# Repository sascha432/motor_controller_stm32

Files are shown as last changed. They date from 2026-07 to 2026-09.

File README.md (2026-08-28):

# DC Motor Controller Firmware for STM32F107/DRV8701

## Software Features

- Start/dashboard workflow for quick motor start-stop and live runtime status
- Selectable control mode: PWM open-loop or RPM-based PID closed-loop
- On-device tuning for speed, brake strength, and stall timeout
- Configurable protection limits for input current, motor current, MOSFET temperature, and motor temperature
- Advanced setup for RPM range, motor direction, and sensor direction
- PID parameter tuning (Kp, Ki, Kd, anti-windup) with live parameter apply and graph
- Diagnostics screen with firmware/PCB info and live min/max telemetry (VCC, current, temperatures, RPM/PWM)
- EEPROM-backed settings with save/restore-defaults from the menu
- LVGL TFT UI with rotary encoder plus dedicated start/back/knob buttons
- Python Tool for configuration and parameter tuning over SWD or USB serial connection

## [Change Log](docs/CHANGELOG.md)

## Hardware Features

- 8-36V, 20A continuous, 40A peak
- Adjustable cycle by cycle motor current limit (0.5-40A)
- Adjustable current limit with signal LED (0.5-40A)
- 1.14" 135x240 TFT display, rotary encoder and 3 buttons for easy navigation
- Support for magnetic encoder MT6701 in A/B mode up to 1024PPR (55000 RPM)
- Dimmable LED with CC driver 3-32V/350mA/5W
- Current, voltage and temperature monitoring

## Current and voltage protection

### Undervoltage Lockout

The controller has an undervoltage lockout (UVLO) threshold of 5.9V. When the supply voltage drops below this threshold, the motor is disabled briefly to allow the supply voltage to recover.

The red LED indicates an undervoltage condition and turns off after the voltage recovers.

### Overvoltage Protection

Overvoltage protection (OVP) is most likely to be triggered while the motor is braking. Back EMF can cause a substantial increase in the supply voltage, potentially blowing the fuse. Adjust the braking strength and OVP threshold carefully; a limit of 32V is generally safe.

At approximately 38V and above, the OVP is disabled, causing all of the energy to be dissipated through the clamping diode and fuse. When OVP is triggered, braking is disengaged, the red LED turns on, and the display shows a motor OVP error.

### Overcurrent Protection

The controller has three configurable current-protection mechanisms.

**NOTE:** the PID parameters must be well tuned for the current limit to work correctly. This applies to closed-loop (RPM-based) mode only.

#### Motor Current Limit

> The maximum current through the motor winding is regulated by a fixed off-time PWM current regulation, or current chopping. When an H-bridge is enabled in forward or reverse drive, current rises through the winding at a rate dependent on the DC voltage and inductance of the winding. After the current hits the current chopping threshold, the bridge enters a brake (low-side slow decay) mode until tOFF has expired.<br>(TI DRV8701 SLVSCX5B –MARCH 2015–REVISED JULY 2015)

This protection operates silently and does not generate a user-facing error.

#### Input Current Limit

When the maximum input current is reached, the motor current limit is gradually reduced until the condition clears. It is then gradually increased again to prevent immediate retriggering. If the motor current limit is set too low, the input current limit may not function correctly.

The yellow LED indicates that the input current limit has been reached and turns off after recovery.

#### Current Limit Strength

The current limit strength determines how fast the motor current is reduced once the input current limit is reached, and how quickly it is restored again after the condition clears. A higher strength reacts more aggressively, whereas a lower strength smooths the reduction and recovery to avoid abrupt current changes.

## Error Codes

The red LED blinks once to indicate an error. The yellow LED then identifies
the error by blinking the corresponding number of times:

| Yellow LED flashes | Description |
|---:|---|
| 1 | A general error was reported |
| 2 | The watchdog interrupt did not respond in time (57ms) |
| 3 | The watchdog timer was not reset in time (1000ms) |
| 4 | The processor encountered a severe, unrecoverable error |
| 5 | The processor accessed memory incorrectly |
| 6 | A critical interrupt occurred that could not be ignored |
| 7 | The processor accessed an invalid or unavailable bus address |
| 8 | The processor detected an invalid instruction or arithmetic operation |

## Navigation

### Rotary Knob Button

- Start screen: open main menu (long press opens advanced menu)
- Dashboard screen: select next value to change (RPM/PWM/PID parameters, etc.), long press selects prev. value

### Start Button

- Start screen: start motor
- Dashboard screen: stop motor

### Back Button

- Start screen: toggle motor direction
- Dashboard screen: stop motor
- Menus: go back to previous menu
- Long press (5 seconds): firmware reset

## Controller schematics and PCB

[Schematics & PCB](https://oshwlab.com/sascha23095123423/project_dzierqaj)

[Schematics PDF](docs/schematic_dc-motor-controller_rev11.pdf)

[Schematics SVG](docs/schematic_dc-motor-controller_rev11.svg)

<a href="docs/schematic_dc-motor-controller_rev11.svg">
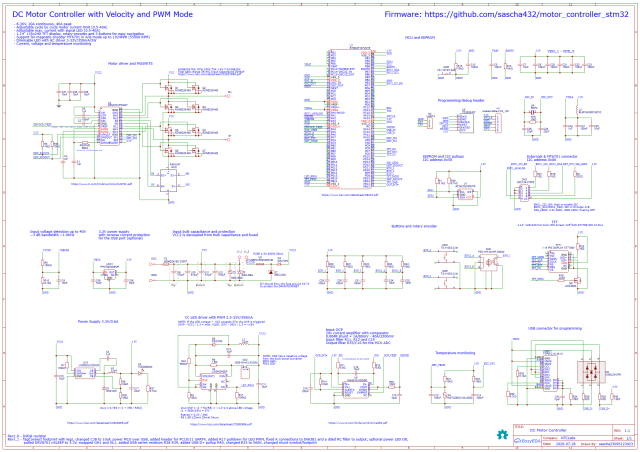
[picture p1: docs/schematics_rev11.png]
Schematic thumbnail
	
</a>

## STL files for motor mount and enclosure

[STL files](stl/STL.md)

## Some pictures

Demonstration of the DC motor controller running a drill press motor

DC motor controller demonstration (https://www.youtube.com/watch?v=RS3WaWhKhmE)

Screenshots

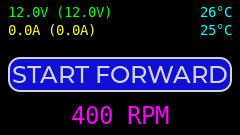
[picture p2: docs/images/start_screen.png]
start_screen

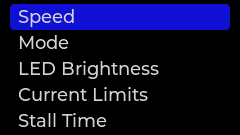
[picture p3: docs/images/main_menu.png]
main_menu

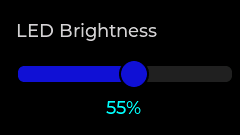
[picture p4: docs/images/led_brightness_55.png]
led_brightness_55


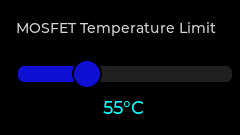
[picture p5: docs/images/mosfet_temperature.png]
mosfet_temperature

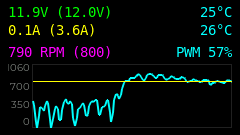
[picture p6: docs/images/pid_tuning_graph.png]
pid_tuning_graph

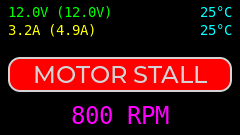
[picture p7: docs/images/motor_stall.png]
motor_stall


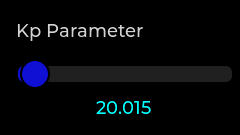
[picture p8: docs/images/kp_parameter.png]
kp_parameter

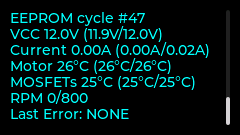
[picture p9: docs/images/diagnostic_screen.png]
diagnostic_screen


Drill press, controller enclosure and PCB

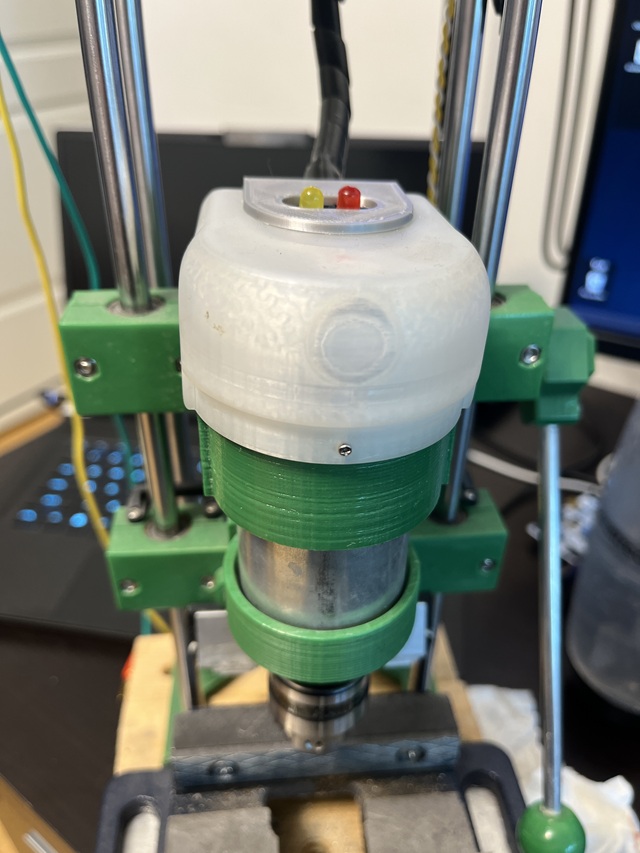
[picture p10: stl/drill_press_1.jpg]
Drill press


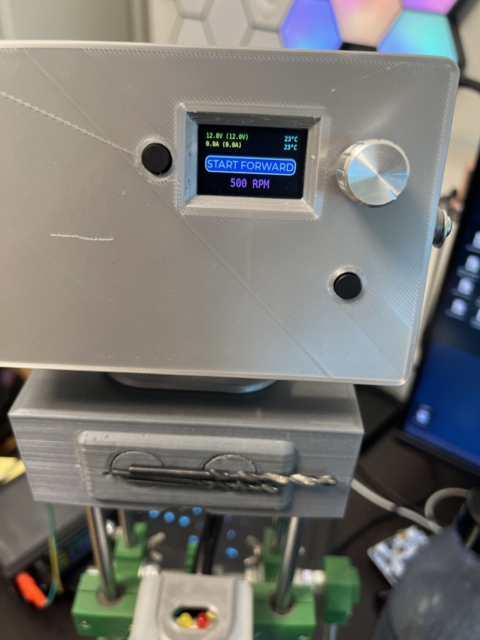
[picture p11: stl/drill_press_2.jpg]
Drill press


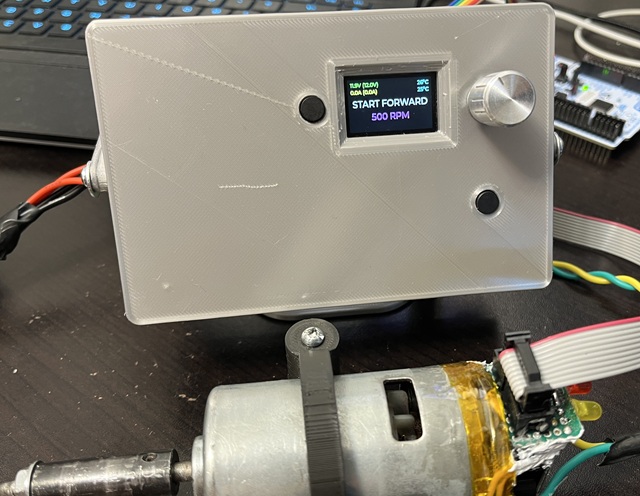
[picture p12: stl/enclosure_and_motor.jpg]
Enclosure and motor


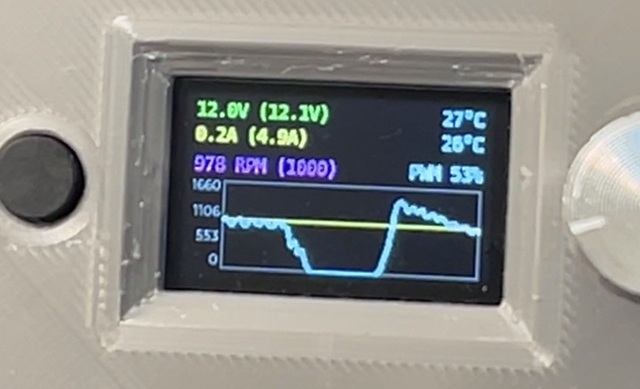
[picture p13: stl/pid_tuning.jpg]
PID tuning


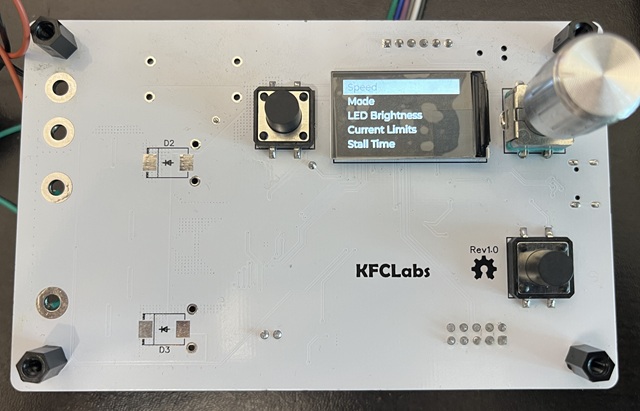
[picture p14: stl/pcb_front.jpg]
PCB front


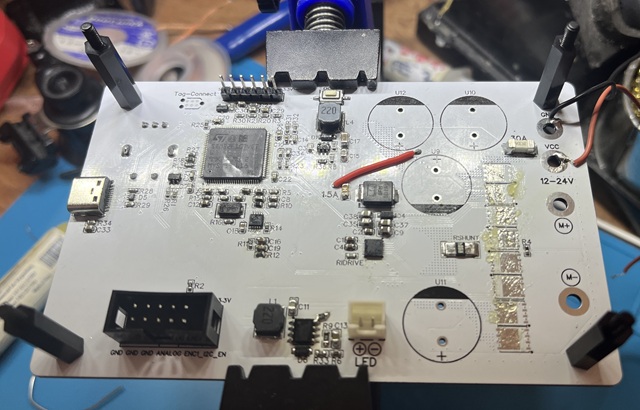
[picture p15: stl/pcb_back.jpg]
PCB back


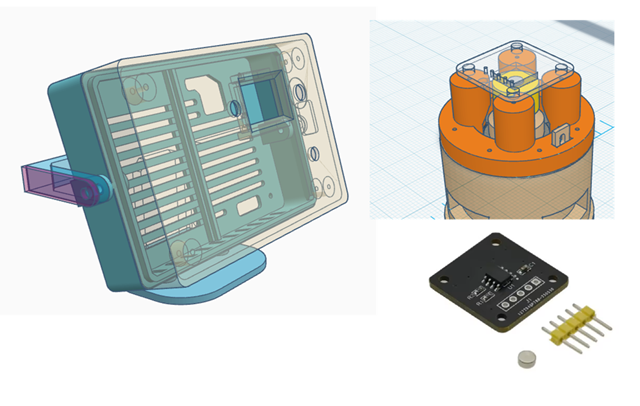
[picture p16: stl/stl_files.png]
STL files and MT6701


PID tuning software

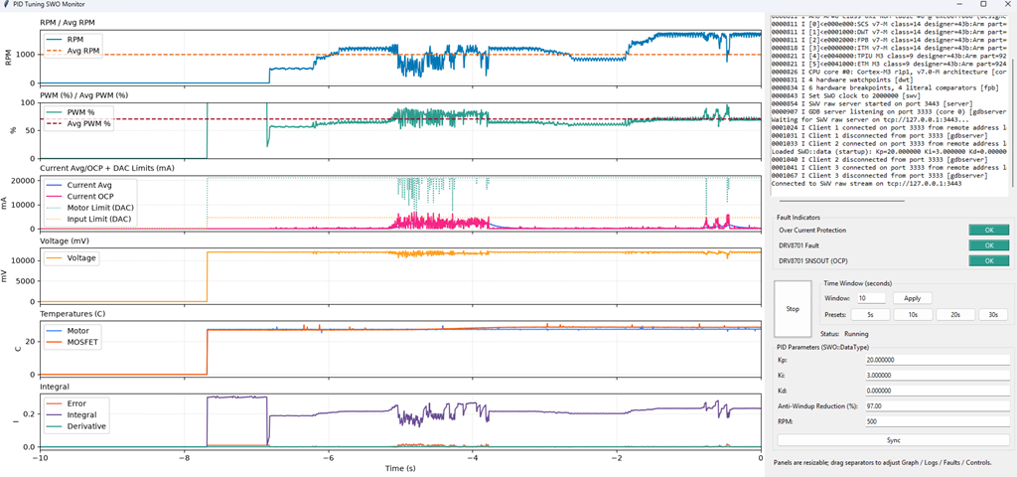
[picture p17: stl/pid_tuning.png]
PID tuning


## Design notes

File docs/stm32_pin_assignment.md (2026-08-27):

<style>
table {
	width: 100%;
	table-layout: fixed;
}
th:nth-child(1), td:nth-child(1) { width: 22%; }
th:nth-child(2), td:nth-child(2) { width: 12%; }
th:nth-child(3), td:nth-child(3) { width: 12%; }
th:nth-child(4), td:nth-child(4) { width: 56%; }
</style>

# STM32F107VCT6 - pin assignments

## Revision: PCB Rev1.0

### DAC output

| Signal | STM32 pin | Type | Notes |
|---|---|---|---|
| DRVOCP_VREF | PA4 | DAC | DAC1_OUT1 |
| OCP_VREF | PA5 | DAC | DAC1_OUT2 |

### ADC input

| Signal | STM32 pin | Type | Notes |
|---|---|---|---|
| EXT_NTC | PC4 | ADC | ADC12_IN14 |
| DRV_TEMP | PC5 | ADC | ADC12_IN15 |
| ISENSE | PA2 | ADC | ADC12_IN2 |
| VSENSE | PA3 | ADC | ADC12_IN3 |
| ENC1_ANALOG | PA1 | DIN | ADC12_IN1/TIM5_CH2 counter |

### QDEC - rotary encoder ENC2

| Signal | STM32 pin | Type | Notes |
|---|---|---|---|
| ENC2_A | PA6 | QDEC | TIM3_CH1 |
| ENC2_B | PA7 | QDEC | TIM3_CH2 |

### QDEC - MT6701 magnetic encoder ENC1

| Signal | STM32 pin | Type | Notes |
|---|---|---|---|
| ENC1_SCL | PB6 | QDEC/I2C | TIM4_CH1 / I2C1_SCL |
| ENC1_SDA | PB7 | QDEC/I2C | TIM4_CH2 / I2C1_SDA |

### PWM output - motor 40 kHz

| Signal | STM32 pin | Type | Notes |
|---|---|---|---|
| DRV_IN2 | PA9 | PWM | TIM1_CH2 |
| DRV_IN1 | PA8 | PWM | TIM1_CH1 |

### PWM output - 1 kHz

| Signal | STM32 pin | Type | Notes |
|---|---|---|---|
| LED_PWM | PB10 | PWM | TIM2_CH3 (remap) - CC LED driver |
| TFT_PWM | PB11 | PWM | TIM2_CH4 (remap) - TFT backlight |

### SPI - TFT display

| Signal | STM32 pin | Type | Notes |
|---|---|---|---|
| TFT_DC | PC7 | DOUT SPI | GPIO data/command |
| TFT_RST | PC6 | DOUT SPI | GPIO reset |
| TFT_CS | PD15 | DOUT SPI | GPIO chip select |
| TFT_MOSI | PB15 | SPI2 | SPI2_MOSI |
| TFT_CLK | PB13 | SPI2 | SPI2_SCK |

### I2C

| Signal | STM32 pin | Type | Notes |
|---|---|---|---|
| SDA1 | PB9 | I2C1 | I2C1_SDA (remap) - 5.1 kOhm pull-up |
| SCL1 | PB8 | I2C1 | I2C1_SCL (remap) - 5.1 kOhm pull-up |

### USB

| Signal | STM32 pin | Type | Notes |
|---|---|---|---|
| USB_DP | PA12 | USB | USB FS D+ |
| USB_DN | PA11 | USB | USB FS D- |

### Debug / programming - TagConnect 6-pin

| Signal | STM32 pin | Type | Notes |
|---|---|---|---|
| SWCLK | PA14 | SWD |  |
| SWDIO | PA13 | SWD |  |
| SWO | PB3 | SWD |  |

### Digital output

| Signal | STM32 pin | Type | Notes |
|---|---|---|---|
| ENC1_I2C_EN | PD7 | DOUT | Enables MT6701 I2C mode |
| MOTOR_LEDS | PD12 | DOUT | 220 Ohm series resistor, charlieplexed red and yellow |

### Digital input - fast interrupt

| Signal | STM32 pin | Type | Notes |
|---|---|---|---|
| DRV_SNSOUT | PD11 | DIN IRQ | Current sense output, falling |
| DRV_FAULT# | PB14 | DIN IRQ | Active-low - DRV8701 fault, falling |
| OCP_INT# | PB12 | DIN IRQ | Active-low - INA381 ALERT#, falling |

### Digital input - interrupt

| Signal | STM32 pin | Type | Notes |
|---|---|---|---|
| BTN_3 | PD10 | DIN IRQ | Start Button, 100 nF debounce cap, rising/falling |
| BTN_2 | PD9 | DIN IRQ | Back Button, 100 nF debounce cap, rising/falling |
| BTN_1 | PD8 | DIN IRQ | Rotary Knob, 100 nF debounce cap, rising/falling |

## Revision: PCB Rev1.1

### UART

| Signal | STM32 pin | Type | Notes |
|---|---|---|---|
| TX4 | PC10 | SERIAL | UART4 TX |
| RX4 | PC11 | SERIAL | UART4 RX |

## Revision: PCB Rev1.2

| Signal | STM32 pin | Type | Notes |
|---|---|---|---|
| USB_PU_EN | PE1 | DOUT | USB pull-up enable in conjunction with VBUS detection |

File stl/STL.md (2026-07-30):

# STL files

This folder contains the .STL files for the MT6701 encoder motor mount and the enclosure for the controller.

## TinkerCad Source files

### 775 Motor Mount For MT6701

https://www.tinkercad.com/things/627dToPH86K-775-motor-mount-for-mt6701-magnetic-encoder

#### Aliexpress MT6701 Module

MT6701 Magnetic Encoder Magnetic Induction Angle Measurement Sensor Module 14bit High Precision Replacement AS5600

The module requires some modifications to enable A/B mode. The controller supports programming over I2C and switching to A/B mode, if the mode selection pin is connected to the controller.

https://www.aliexpress.com/item/1005005796758249.html

### Controller Enclosure

https://www.tinkercad.com/things/fNIPaWNxDLo-motor-controller-enclosure

## Pictures

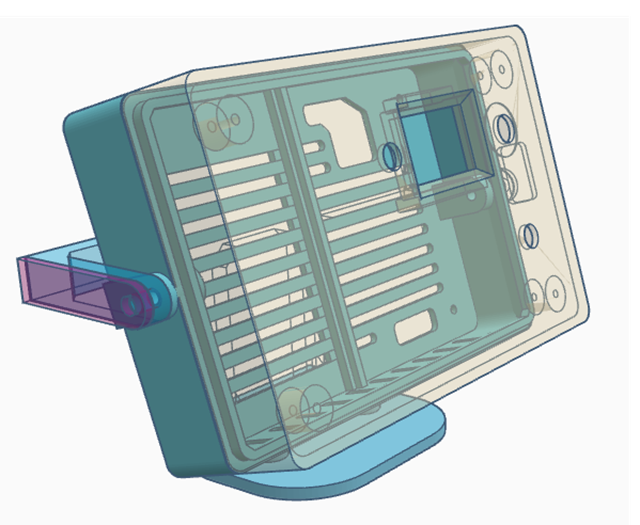
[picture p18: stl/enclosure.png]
Controller Enclosure


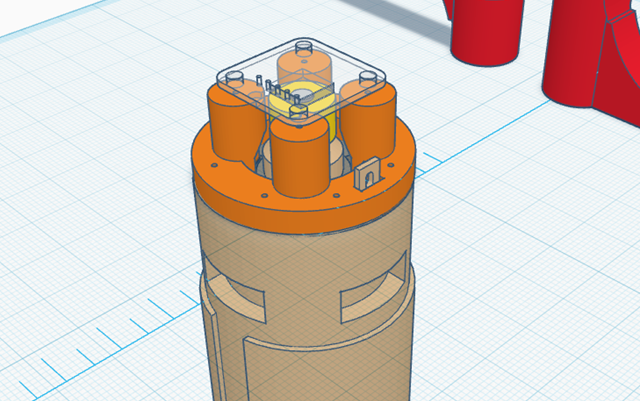
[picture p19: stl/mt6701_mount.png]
MT6701 Motor Mount


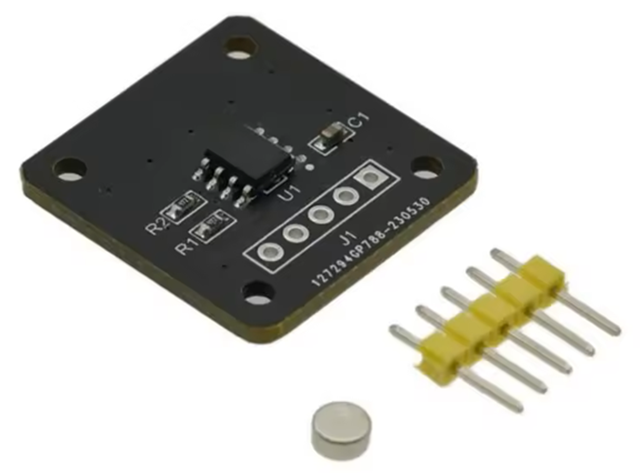
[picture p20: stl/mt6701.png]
MT6701 Module


PCB front

PCB back

Enclosure and motor

PID tuning

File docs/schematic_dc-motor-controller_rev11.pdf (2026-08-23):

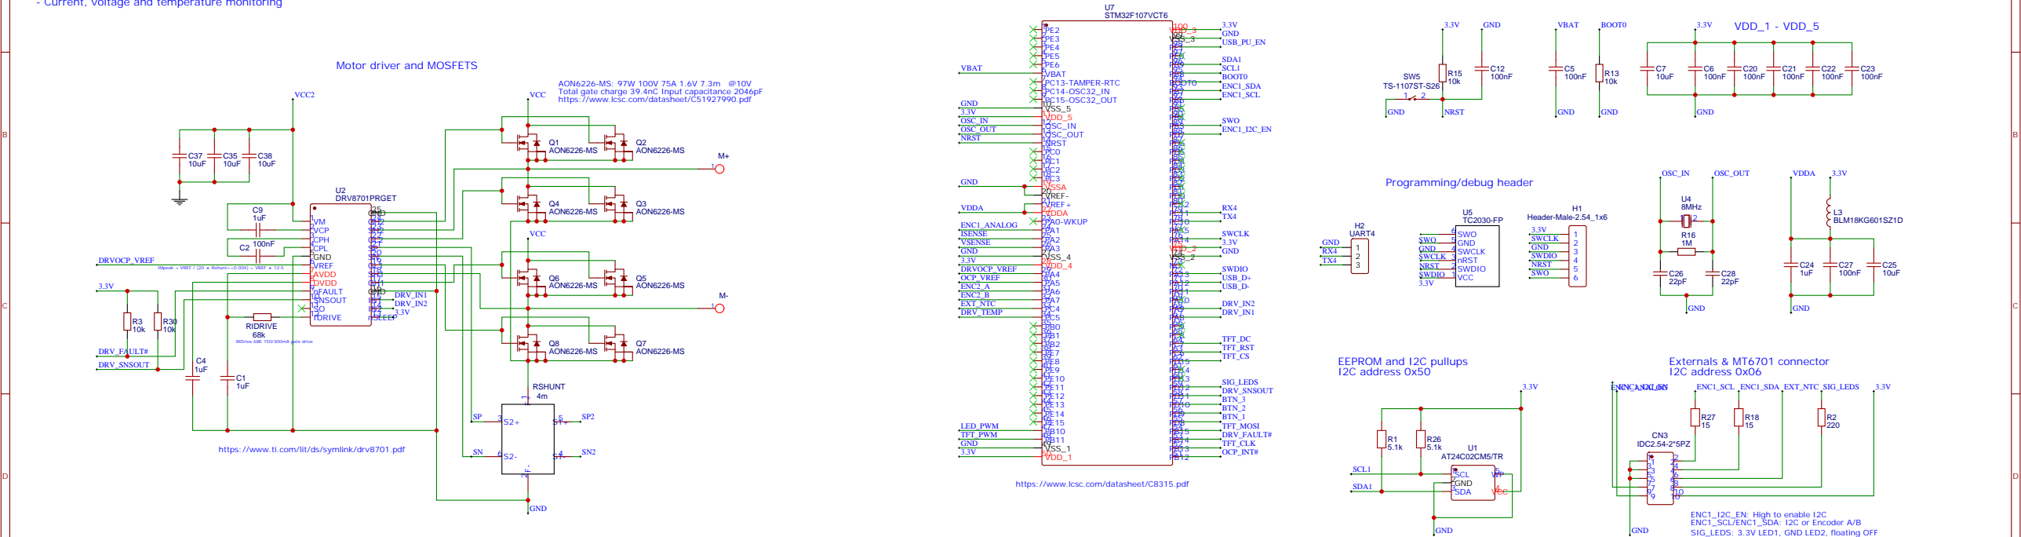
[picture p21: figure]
AON6226-MS; DRV8701PRGET; VM 1 VCP 2 CPH 3 CPL 4 GND 5 VREF 6 AVDD 7 DVDD 8 nFAULT 9 SNSOUT 10 SO 11; RIDRIVE; DRV_IN2; DRV_IN1; DRVOCP_VREF; IMpeak = VREF / (20; Rshunt==0.004) = VREF; RiDrive 68K 150/300mA gate drive; Motor driver and MOSFETS; DRV_FAULT#; STM32F107VCT6; 5 VBAT; 6 PC13-TAMPER-RTC; 7 PC14-OSC32_IN; 8 PC15-OSC32_OUT; 9 VSS_5; 10 VDD_5; 11 OSC_IN; 12 OSC_OUT; 13 NRST; 18 VSSA; 19 VREF-; 20 VREF+; 21 VDDA; 22 PA0-WKUP; 26 VSS_4; 27 VDD_4; 48 VSS_1; 49 VDD_1; VSS_2; VDD_2; BOOT0; VSS_3; VDD_3; SCL; 1 GND; 2 SDA; VCC; DRVOCP_VREF OCP_VREF; SDA1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

IDRIVE 12 | nSLEEP 13 IN214 IN115 GND 16 GH1 17 SH1 18 GL1 19 SN20 SP21 GL2 22 SH2 23 GH2 24 GND 25

## Input bulk capacitance and protection VCC2 is decoupled from bulk capacitance and fused

## CC LED driver with PWM 2.5-32V/350mA

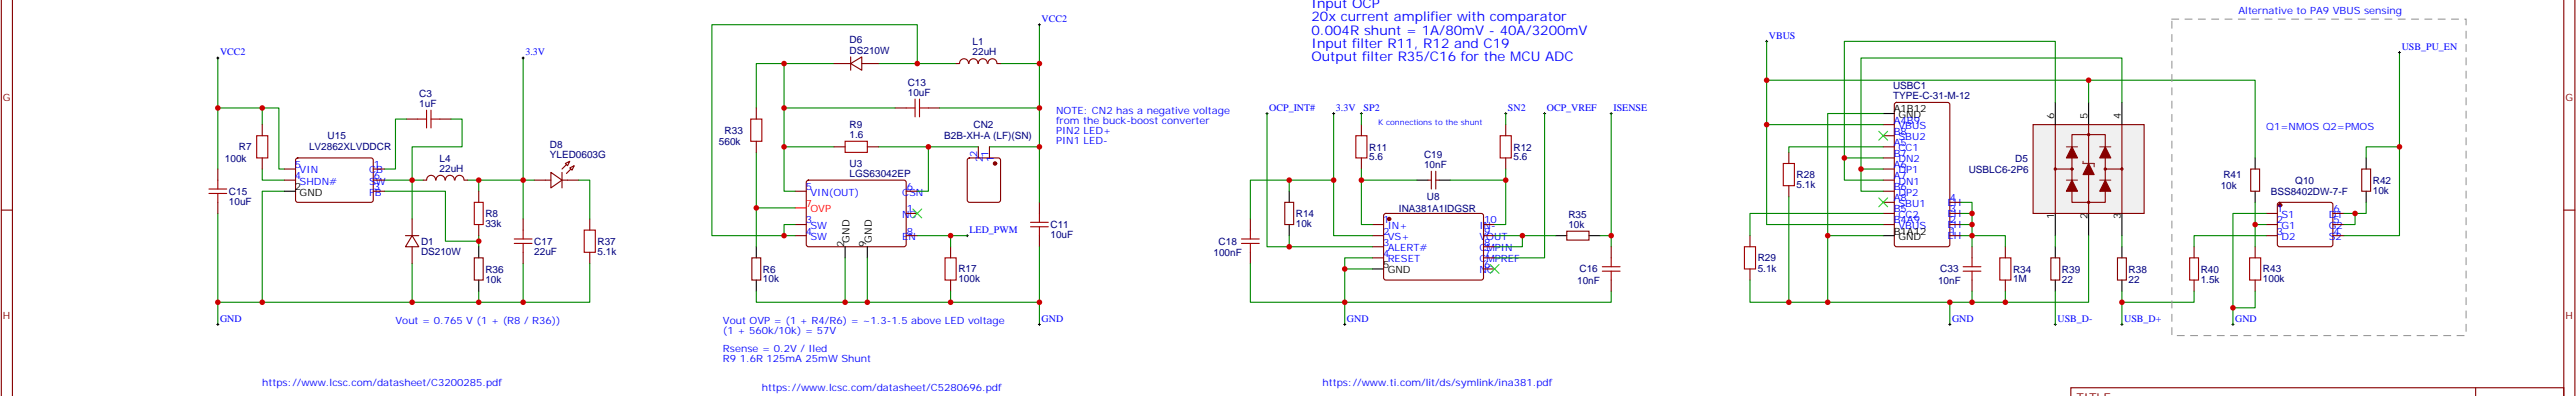
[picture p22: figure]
LED_PWM; LGS63042EP; VIN(OUT) 5; CSN 6; GND; OVP 7 SW3 SW4; INA381A1IDGSR; 10 VOUT; 9 CMPIN; 8 CMPREF; 6 GND; RESET; ALERT#; ISENSE; 20x current amplifier with comparator 0.004R shunt = 1A/80mV - 40A/3200mV Input filter R11, R12 and C19 Output filter R35/C16 for the MCU ADC; OCP_VREF; OCP_INT#; TYPE-C-31-M-12; USBC1; A1B12 VBUS; A4B9 SBU2; B6 SBU1; B5 VBUS; B4A9 GND; USBLC6-2P6; LV2862XLVDDCR; GND 2; SHDN# 4; VIN 5; Vout = 0.765 V (1 + (R8 / R36)); NOTE: CN2 has a negative voltage from the buck-boost converter PIN2 LED+ PIN1 LED-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

Vout OVP = (1 + R4/R6) = ~1.3-1.5 above LED voltage

A | A
E | E
F | F

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
### TITLE:

DC Motor Controller | REV: 1.2
Date: | 2026-07-28

### Sheet: 1/1

## Drawn By: sascha23095123423

### Company: KFCLabs

100k

R5

9.1k

R10

VSENSE

## Input voltage detection up to 40V 3 dB bandwidth ~1.9KHz

## Input OCP

## MCU and EEPROM

1.14 IPS DISPLAY ST7789V

TFT1

TP0

1
TP1

2
SDIN

3
SCLK

4
RS

5
RES

6
CS
7 | GND
| 8

NC

9

VDD

10

LED-

11

LED+

12

GND

13

PEC11R-4015F-S0024

SW1

B

C

A | 1
| 2

TS-1103S-C-M

SW2

3 | 4
1 | 2

TFT_CLK

TFT_MOSI

AO3400A

Q9

220

R19
TFT_PWM

TFT_RST
TFT_CS

TFT_DC
10k

R20

100nF

C29
100nF

C30

10k

R21
10k

R22

100nF

C31

10k

R23
10k

R24

10nF

C34
10nF

C32

BTN_1 | BTN_2 | BTN_3 | ENC2_A | ENC2_B

## Buttons and rotary encoder

ENC2_A | BTN_1

ENC2_B

TS-1103S-C-M

SW3

3 | 4
BTN_3 | 1 | 2

BTN_2

## TFT

15

R25

VCC

1

GND

1

1.14" 135x240 Full Color IPS Screen 135*240 ST7789 SPI 13 Pins

- 8-36V, 20A continuous, 40A peak - Adjustable cycle by cycle motor current limit (0.5-40A) - Adjustable max. current with signal LED (0.5-40A) - 1.14" 135x240 TFT display, rotary encoder and 3 buttons for easy navigation - Support for magnetic encoder MT6701 in A/B mode up to 1024PPR (55000 RPM) - Dimmable LED with CC driver 3-32V/350mA/5W - Current, voltage and temperature monitoring

# DC Motor Controller with Velocity and PWM Mode

10k

R31

DRV_TEMP

10k

R32

## Temperature monitoring

KNTC0603/10KJ3950

R4

EXT_NTC

470uF

U9
470uF

U10
470uF

U11
470uF

U12
SMCJ58A

D2

BSMD2410C-2300T

F2
F1206FA1500V063TM

U6

D7 should blow the fuse around 43.7V to protect the DRV8701PRGET

## USB connector for programming (optional) Power Supply 3.3V/0.6A

DS210W

D4

10nF

C8

SMCJ33A

D7

100nF

C10
100nF

C14

SMCJ58A

D3

J1_1

1

J1_2

1 VCCJP

Total gate charge 39.4nC Input capacitance 2046pF

Top | Bottom | Top Bottom

FUSE 1.5A 400% 50ms

## Rev1.0 - Initial revision

Rev1.1 - TagConnect footprint with legs, changed C38 to 10uF, power MCU over USB, added header for PC10/11 UART4, added R17 pulldown for LED PWM, fixed K connections to INA381 and a dded RC filter to output, optional power LED D8, pulled DRV8701 nSLEEP to 3.3V, swapped GH1 and GL1, added USB series resistors R38 R39, added USB D+ pullup R40, changed R33 to 560K, changed shunt symbol/footprint

## Rev 1.2 - Removed USB LDO (self powered) and added VBUS sensing

SIG_LEDS: 3.3V LED1, GND LED2, floating OFF

# Firmware: https://github.com/sascha432/motor_controller_stm32

VCCJP | VCC | VCC2
3.3V

3.3V

3.3V

GND | GND | GND | GND | GND

GND

NOTE: If the LED voltage + VCC exceeds 57V, the OVP is triggered (OVP - VCC) / 1.3 = max. VLED, (57V - 36V) / 1.3 = ~16V

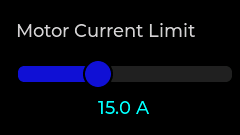
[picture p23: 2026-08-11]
docs/images/motor_current_limit.png

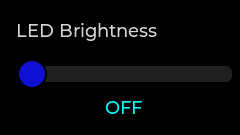
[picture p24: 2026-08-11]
docs/images/led_brightness_0.png

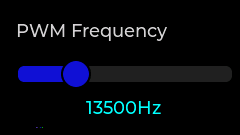
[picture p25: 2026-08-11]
docs/images/pwm_frequency.png

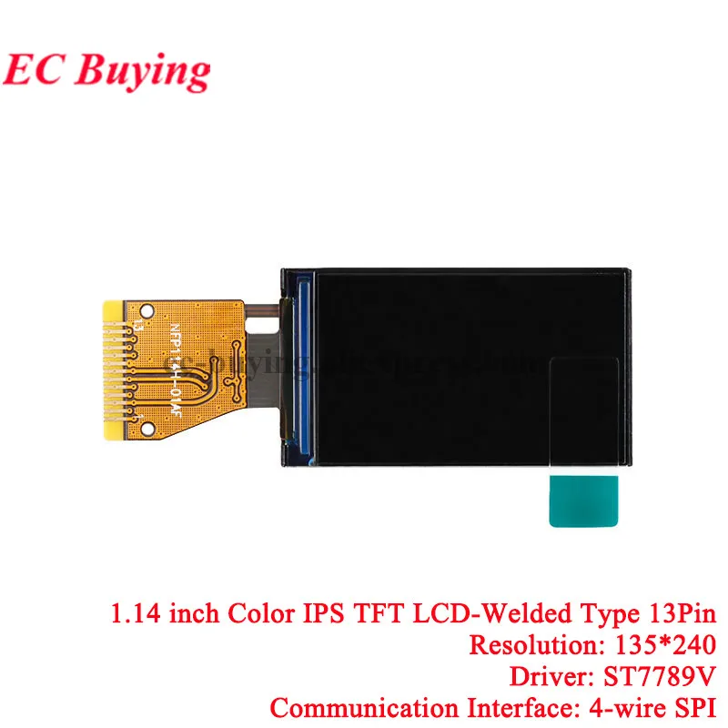
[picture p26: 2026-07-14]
docs/datasheets/TFT_pic.webp

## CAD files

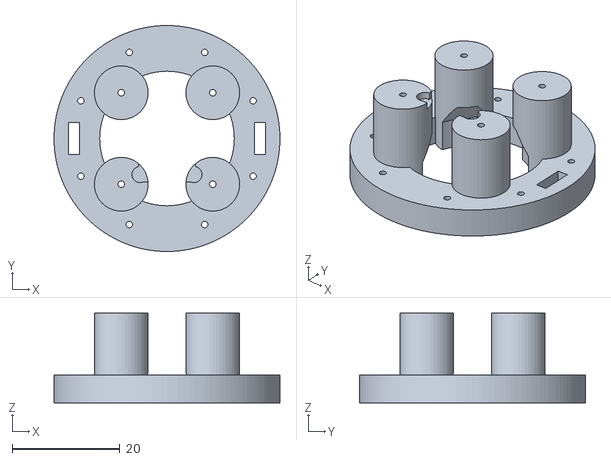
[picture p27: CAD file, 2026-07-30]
stl/mt6701_775_mount.stl
42.0 x 42.0 x 16.7

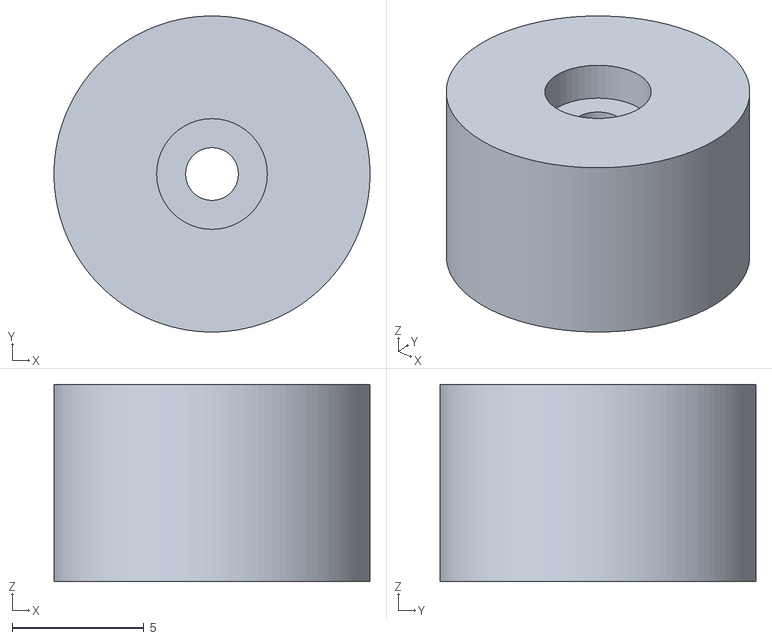
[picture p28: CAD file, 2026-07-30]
stl/mt6701_775_magnet_mount.stl
12.0 x 12.0 x 7.50

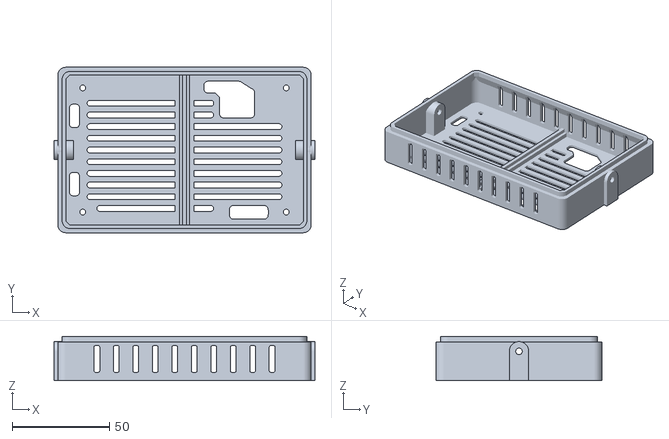
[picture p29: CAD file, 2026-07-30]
stl/enclosure_bottom.stl
134.0 x 85.0 x 22.7

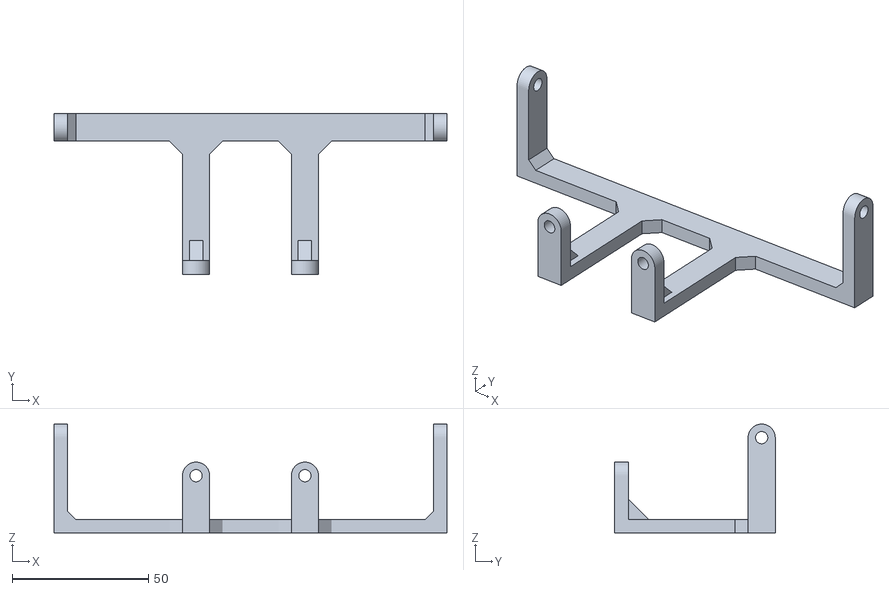
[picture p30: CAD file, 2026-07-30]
stl/enclosure_mount.stl
144.4 x 59.0 x 40.0

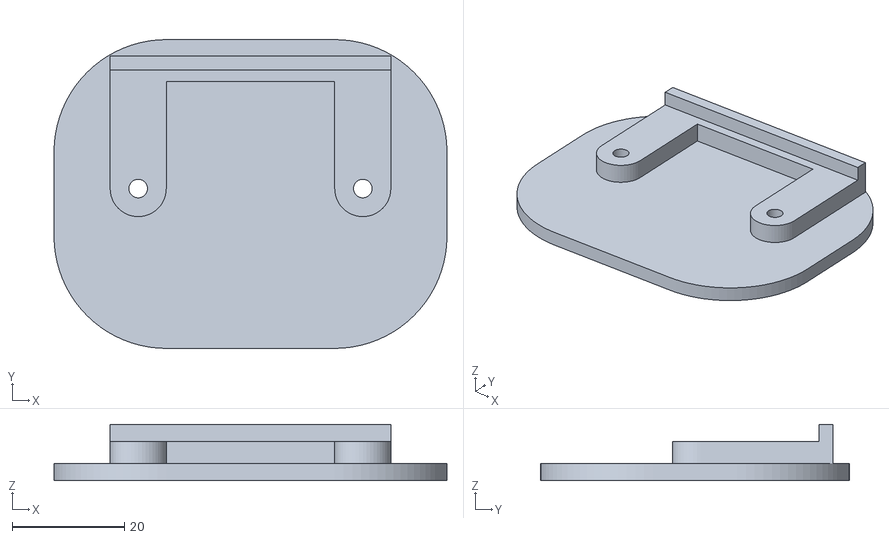
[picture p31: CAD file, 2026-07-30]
stl/enclosure_mount_bottom_plate.stl
70.0 x 55.0 x 10.00

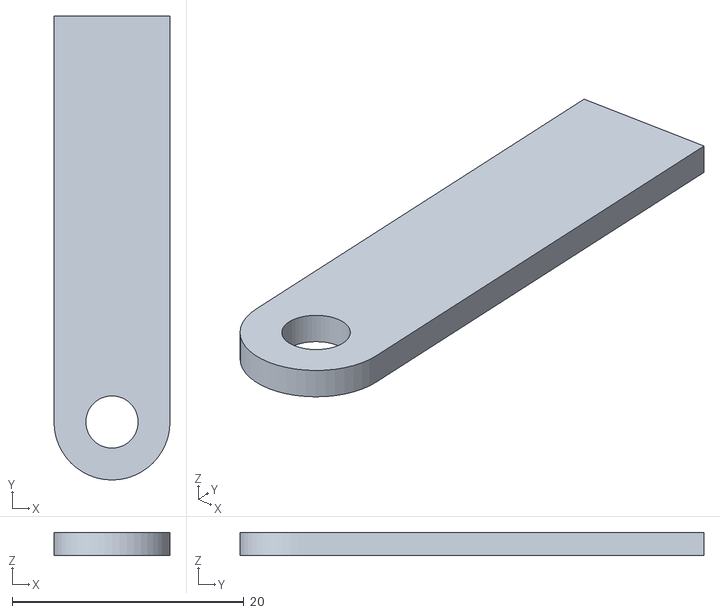
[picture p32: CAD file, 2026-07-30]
stl/enclosure_mount_side_reinforcement.stl
10.0 x 40.0 x 2.00

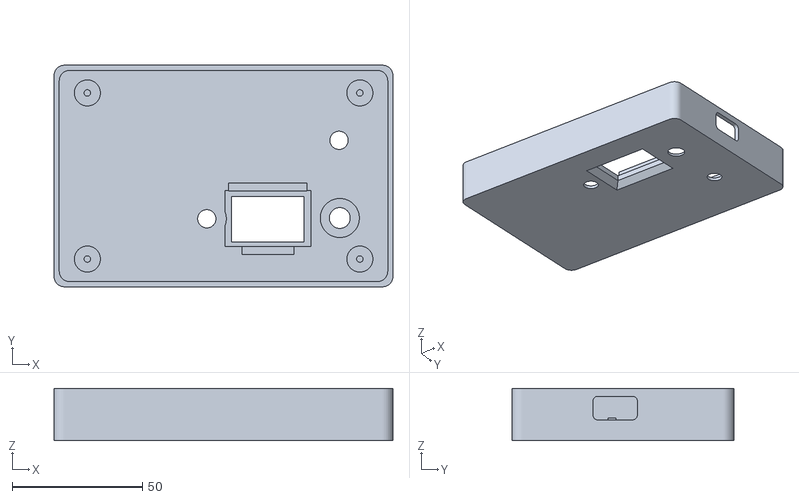
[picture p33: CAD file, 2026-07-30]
stl/enclosure_top.stl
130.0 x 85.0 x 20.1

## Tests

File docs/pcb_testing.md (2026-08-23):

# TEST TEST

## This document contains the test protocol

### Rev 1.0

- 3.3V supply produces 3.27-3.29V, tested up to 200ma
- LED cc driver produces 122mA for a 12V LED, shorted with mA range (50R?) 127mA
- LED driver 27.09V disconnected max. voltage
- USB connector and diode checked
- MCU working
- DRV8701 no shorts
- TFT, knob, buttons are working
- TFT backlight working
- LED lightning: added pulldown to pwm to avoid flashing during reset
- INA K connections fixed and output filter added
- INA alert# triggers interrupt
- DRV8701 powers up without faults after providing 3.3v on nSLEEP
- Motor LEDs working, floating seems to cause minor glow
- 4 ADC channels working current, voltage, 2x temp.
- DAC outputs working DRV8701 vref and INA381 comparator vref
- AT24C02CM5 EEPROM is working
- DRV8701 fault after turning PWM on.. fixed swapped GL1 GH1 pins
- motor is running with PWM
- PID controller is regulating
- DRV8701 current limit and INA OCP working
- USB not detecting any device - CC1/CC2 resistors working, D+/- connected to MCU DP DN, tvs diode right direction
- MT6701 analog sensor working as counter to check if the motor turns
- SMCJ33A clamping to 38.7V when braking from high RPM
- fixed issue with high LED string voltage by increasing the OVP to 57V, tested 8-40V input with 26-27V output and pwm dimming, stops around 30V input reaching the 57V OVP

### Rev 1.1

Untested

### Rev 1.2

- USB link detection/vbus sensing instead of PA9 vbus sensing

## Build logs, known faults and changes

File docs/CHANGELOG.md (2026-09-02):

# Changelog

## [Unreleased 1.0.3]

- New version

## 1.0.2

- Settings Tuning enabled for Open Loop Mode
- Added current limit strength (Low - Very High)
- Added LVGL double buffering with DMA interrupts to improve display performance
- Terminal connected detection to avoid USB timeouts and lag
- Using ADC injection group and interrupt to handle over current and voltage
- Device controlled USB D+ pull-up

## 1.0.1

- USB debug output disabled inside ISRs
- Improved display performance by removing the big endian conversion before transferring data via DMA
- Added support for USB Device Id as serial port to motor_config.py

## 1.0.0

- Initial version

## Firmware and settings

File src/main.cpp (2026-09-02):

/**
  Author: sascha_lammers@gmx.de
*/

#include "i2c.h"
#include "controls.h"
#include "mt6701_encoder.h"
#include "pid_controller.h"
#include "adc.h"
#include "leds.h"
#include "tft_driver.h"
#include "tft_driver_screenshot.h"
#include "ui.h"
#include "menu.h"
#include "eeprom.h"
#include "stats.h"
#include "helpers.h"
#include "serial.h"
#include "debug.h"

#if LV_USE_LOG
static void lvgl_log_cb(const char *buf)
{
    DEBUG_PRINT_MSG(DebugType::LVGL, "%s", buf ? buf : "<null>");
}
#endif

/**
 * @brief Initialize interrupt handlers
 *
 */
static inline void EXTI_Init()
{
    // Route EXTI8-EXTI11 to GPIO port D
    AFIO->EXTICR[2] =
        AFIO_EXTICR3_EXTI8_PD  |    // EXTI8  PD8
        AFIO_EXTICR3_EXTI9_PD  |    // EXTI9  PD9
        AFIO_EXTICR3_EXTI10_PD |    // EXTI10 PD10
        AFIO_EXTICR3_EXTI11_PD;     // EXTI11 PD11

    // Route EXTI14 to GPIO port B
    AFIO->EXTICR[3] =
        AFIO_EXTICR4_EXTI14_PB;     // EXTI14 PB14

    // Clear pending flags
    EXTI->PR =
        BTN_1_Pin       |   // PD8  BTN_1
        BTN_2_Pin       |   // PD9  BTN_2
        BTN_3_Pin       |   // PD10 BTN_3
        DRV_SNSOUT_Pin  |   // PD11 DRV_SNSOUT
        DRV_FAULT_Pin;      // PB14 DRV_FAULT

    // Enable interrupt lines
    EXTI->IMR |=
        BTN_1_Pin       |   // PD8  BTN_1
        BTN_2_Pin       |   // PD9  BTN_2
        BTN_3_Pin       |   // PD10 BTN_3
        DRV_SNSOUT_Pin  |   // PD11 DRV_SNSOUT
        DRV_FAULT_Pin;      // PB14 DRV_FAULT

    // Rising edge: button change interrupt
    EXTI->RTSR |=
        BTN_1_Pin       |   // PD8  BTN_1
        BTN_2_Pin       |   // PD9  BTN_2
        BTN_3_Pin       |   // PD10 BTN_3
        DRV_SNSOUT_Pin  |   // PD11 DRV_SNSOUT
        DRV_FAULT_Pin;      // PB14 DRV_FAULT

    // Falling edge: button change + fault inputs
    EXTI->FTSR |=
        BTN_1_Pin       |   // PD8  BTN_1
        BTN_2_Pin       |   // PD9  BTN_2
        BTN_3_Pin       |   // PD10 BTN_3
        DRV_SNSOUT_Pin  |   // PD11 DRV_SNSOUT
        DRV_FAULT_Pin;      // PB14 DRV_FAULT

    // Enable NVIC
    HAL_NVIC_EnableIRQ(EXTI9_5_IRQn);
    HAL_NVIC_EnableIRQ(EXTI15_10_IRQn);

    HAL_NVIC_SetPriority(TIM6_IRQn, 1, 0);
    HAL_NVIC_EnableIRQ(TIM6_IRQn);
}

/**
 * @brief Disable PID, PWM and invoke system reset
 *
 */
static inline void invoke_system_reset()
{
    pid.running = false;
    PID_WRITE_MOTOR_PWM_OFF();
    HAL_NVIC_SystemReset();
}

/**
 * @brief Core setup
 *
 */
static inline void setup()
{
    // Initialize and read EEPROM on I2C1 on PB8/PB9
    eeprom.init();
    eeprom.read();

    // motor encoder
    motorEncoder.init();

    // buttons
    knobButton.init();
    backButton.init(nullptr, [](uint32_t duration) {
        // do hard reset after holding the back button
        if (duration >= UIConstants::kResetFirmwareLongPressTimeout) {
            invoke_system_reset();
        }
    });
    startButton.init();

    // ADC with DMA
    adc.init();
    // PID controller
    pid.init();
    // apply parameters
    pid.applyPIDParams();

    // Initialize display GPIO and SPI
    tft_driver_gpio_init();
    tft_driver_spi_init();
}

/**
 * @brief User setup
 *
 */
static inline void user_setup()
{
    // Initialize display driver
    tft_driver_init();
    tft_clear_display();

    // start the watchdog after startup is complete
    WatchDog::init();
    MX_WWDG_Init();

    // Initialize LVGL and register flush callback
    lv_init();
    #if LV_USE_LOG
        lv_log_register_print_cb(lvgl_log_cb);
    #endif
    tft_driver_lvgl_init();

    // Show welcome screen and load main menu
    menu.loadWelcomeScreen();
    // Apply settings after welcome screen since it turns the backlight on
    menu.applyEEPROMSettings();

    // program MT6701 PPR via I2C
    if constexpr (PidController::kProgramPPR) {
        motorEncoder.programPPR(PidController::kPPR);
    }

    menu.loadStartScreen();
}

#if HAVE_USB_DEVICE

/**
 * @brief Handle incoming serial data
 *
 */
static inline void handle_serial_data(Serial::BinaryResult result, const char *buf)
{
    switch(result.type) {
        case Serial::BinaryType::REQUEST_SCREENSHOT: {
                DEBUG_PRINT(DebugType::INFO, "Serial: screenshot requested");
                SWO::data.sendScreenshot = true;
            }
            break;
        case Serial::BinaryType::TOGGLE_PID: {
                const uint32_t value = *reinterpret_cast<const uint32_t *>(buf);
                SWO::data.enabled = value ? SWO::EnableState::SERIAL : SWO::EnableState::DISABLED;
                DEBUG_PRINT(DebugType::INFO, "Serial: PID tuning %s", value ? "enabled" : "disabled");
                if (value) {
                    const auto params = pid.getPidParameters();
                    Serial::writeBinary(Serial::BinaryType::PARAMETERS, &params, sizeof(params));
                }
            }
            break;
        case Serial::BinaryType::REQUEST_PARAMETERS: {
                DEBUG_PRINT(DebugType::INFO, "Serial: PID parameters requested");
                const auto params = pid.getPidParameters();
                Serial::writeBinary(Serial::BinaryType::PARAMETERS, &params, sizeof(params));
            }
            break;
        case Serial::BinaryType::PARAMETERS: {
                DEBUG_PRINT(DebugType::INFO, "Serial: PID parameters received");
                pid.setPidParameters(*reinterpret_cast<const PidController::PidParameters *>(buf));
            }
            break;
        case Serial::BinaryType::REQUEST_EEPROM: {
                DEBUG_PRINT(DebugType::INFO, "Serial: EEPROM requested");
                const EEPROM::Data &data = eeprom.getData();
                Serial::writeBinary(Serial::BinaryType::EEPROM, &data, sizeof(data));
            }
            break;
        case Serial::BinaryType::EEPROM: {
                eeprom.getData() = *reinterpret_cast<const EEPROM::Data *>(buf);
                const bool result = eeprom.write();
                (void)result;
                DEBUG_PRINT(DebugType::INFO, "Serial: EEPROM write=%u", static_cast<unsigned>(result));
                menu.applyEEPROMSettings();
            }
            break;
        case Serial::BinaryType::SYSTEM_RESET: {
                DEBUG_PRINT(DebugType::INFO, "Serial: system reset requested");
                invoke_system_reset();
            }
            break;
        default:
            DEBUG_PRINT(DebugType::ERROR, "Serial: binary type=%u size=%u", static_cast<unsigned>(result.type), static_cast<unsigned>(result.size));
            break;
    }
}

#endif

/**
 * @brief Main loop function
 *
 */
static inline void loop()
{
    // feed the dog
    WatchDog::feed();

    // handle buttons
    uint32_t dur;
    if ((dur = knobButton.isReleased()) != 0) {
        menu.handleButtonPress(dur);
    }
    if (backButton.isReleased()) {
        menu.handleBackButtonPress();
    }
    if (startButton.isReleased()) {
        menu.handleStartButtonPress();
    }

    if (LEDs::isAnyLEDOn()) {
        // check if fault/errors have cleared
        if (
            // check for errors set
            !pid.hasErrorCode() &&
            // check for DRV fault
            !pid.faults.drv8701Fault &&
            // check OCP condition
            !pid.ocp.isActive()
        ) {
            // turn LEDs off
            LEDs::off();
        }
    }

    if (pid.running) {
        // check NTC sensors, not time critical and a couple times per seconds is enough
        if (ADCConverter::NTC::compare(adc.getMotorTemperatureFiltered(), eeprom.getMotorTemperatureLimitADC()) > 0) {
            pid.setErrorCode(PidController::ErrorCodeType::MOTOR_OVER_TEMPERATURE);
        }
        else if (ADCConverter::NTC::compare(adc.getMosfetTemperatureFiltered(), eeprom.getMosfetTemperatureLimitADC()) > 0) {
            pid.setErrorCode(PidController::ErrorCodeType::MOSFET_OVER_TEMPERATURE);
        }
    }

    if (SWO::data.EEPROM.commit) {
        // check if the PID tuning requests to save the EEPROM settings
        SWO::data.EEPROM.commit = false;
        const bool result = eeprom.write();
        (void)result;
        DEBUG_PRINT(DebugType::INFO, "SWO EEPROM write=%u", result);
        menu.applyEEPROMSettings();
    }

    #if HAVE_SCREENSHOTS
        bool screenshotRequested = false;
        // check if a screenshot was requested
        if (SWO::data.sendScreenshot) {
            SWO::data.sendScreenshot = false;
            screenshotRequested = screenshot.begin();
            if (screenshotRequested) {
                DEBUG_PRINT(DebugType::INFO, "Screenshot started");
                lv_obj_invalidate(lv_scr_act());
            }
            else {
                DEBUG_PRINT(DebugType::INFO, "Screenshot failed to start");
            }
        }
    #else
        constexpr bool screenshotRequested = false;
    #endif

    // handle ui updates and rotary encoder
    static uint32_t lastLvHandler = 0;
    if ((HAL_GetTick() - lastLvHandler) >= 5 || screenshotRequested) {
        // handle rotary encoder
        int32_t delta = knob.getPositionDelta();
        if (delta) {
            int32_t newPosition = menu.updateRotaryValue(delta);
            (void)newPosition;
            DEBUG_PRINT(DebugType::UI, "main() menu=%d rotary_delta=%d", newPosition, delta);
        }
        // handle LVGL updates
        ScreenFlow &screenFlow = menu.getScreenFlow();
        switch(screenFlow->getId()) {
            case Screen::Type::DASHBOARD:
                if (pid.hasErrorCode()) {
                    // return to start screen
                    menu.loadStartScreen();
                    break;
                }
                // fallthrough
            case Screen::Type::START:
            case Screen::Type::DIAGNOSTICS:
                stats.update();
                screenFlow->update();
                break;
            default:
                break;
        }

        // update UI, this might take a couple 100ms
        #if HAVE_DWT_TICK_PROFILER && false
            TickProfiler::start(8);
            screenFlow.refresh();
            TickProfiler::stop();
            DEBUG_PRINT_MSG(DebugType::UI, "%u\n", TickProfiler::getTicks());
        #else
            screenFlow.refresh();
        #endif

        #if HAVE_SCREENSHOTS
            // finalize requested screenshot
            if (screenshotRequested) {
                screenshot.end();
                DEBUG_PRINT(DebugType::INFO, "Screenshot sent");
            }
        #endif
        // DEBUG_PRINT_MSG(DebugType::UI, "lv_timer_handler=%ums\n", HAL_GetTick() - lastLvHandler);
        lastLvHandler = HAL_GetTick();
    }

    #if 0
        static uint32_t lastDebugPrint = 0;
        if ((HAL_GetTick() - lastDebugPrint) >= 100U) {
            DEBUG_PRINT(DebugType::INFO, "abc=%u", 123);
            lastDebugPrint = HAL_GetTick();
        }
    #endif

    #if LV_MEM_DEBUG
        static uint32_t lastMemStats = 0;
        if ((HAL_GetTick() - lastMemStats) >= 1000U) {
            lv_mem_monitor_t monitor;
            lv_mem_monitor(&monitor);
            DEBUG_PRINT(DebugType::MEM,
                "LVGL heap total=%lu free=%lu used=%u%% frag=%u%% largest=%lu max=%lu allocs=%lu free_cnt=%lu",
                static_cast<unsigned long>(monitor.total_size),
                static_cast<unsigned long>(monitor.free_size),
                static_cast<unsigned>(monitor.used_pct),
                static_cast<unsigned>(monitor.frag_pct),
                static_cast<unsigned long>(monitor.free_biggest_size),
                static_cast<unsigned long>(monitor.max_used),
                static_cast<unsigned long>(monitor.used_cnt),
                static_cast<unsigned long>(monitor.free_cnt)
            );
            lastMemStats = HAL_GetTick();
        }
    #endif

    #if HAVE_USB_DEVICE
        // handle USB CDC data
        if (Serial::isConnected()) {
            char buf[128]; // EEPROM::Data is 60 byte, the header is 12 byte + a lot extra space
            Serial::BinaryResult result = Serial::readBinary(buf, sizeof(buf));
            if (result.size) {
                uint32_t newCrc;
                if ((result.size % sizeof(uint32_t)) != 0) {
                    DEBUG_PRINT(DebugType::ERROR, "Serial: invalid binary type=%u size=%u", static_cast<unsigned>(result.type), static_cast<unsigned>(result.size));
                }
                else if ((newCrc = stm32_CRC(reinterpret_cast<uint32_t *>(buf), result.size)) != result.crc) {
                    DEBUG_PRINT(DebugType::ERROR, "Serial: CRC expected=0x%08X got=0x%08X type=%u size=%u", result.crc, newCrc, static_cast<unsigned>(result.type), static_cast<unsigned>(result.size));
                }
                else {
                    handle_serial_data(result, buf);
                }
            }
        }
    #endif

    if (SWO::data.enabled == SWO::EnableState::SWO) {
        if (SWO::isPortWritable(SWO::kPidPort)) {
            // send PID tuning data
            PidController::PidLoopType item;
            while (pid.pidLoopBuffer.pop(item)) {
                if (!SWO::writeByteFast(SWO::kPidPort, sizeof(item)) || !SWO::writeFast(SWO::kPidPort, item)) {
                    pid.pidLoopBuffer.clear();
                    break;
                }
            }
        }
    }
    #if HAVE_USB_DEVICE
    else if (SWO::data.enabled == SWO::EnableState::SERIAL) {
        // send PID tuning data
        PidController::PidLoopType item;
        while (pid.pidLoopBuffer.pop(item)) {
            if (Serial::writeBinary(Serial::BinaryType::PID, &item, sizeof(item)) != sizeof(item)) {
                pid.pidLoopBuffer.clear();
                break;
            }
        }
    }
    #endif
}

/**
 * @brief Main function
 *
 */
int main(void)
{
    // system init
    HAL_Init();
    LEDs::init();
    DWT_Init();
    SystemClock_Config();
    SWO::init();
    MX_CRC_Init();
    MX_TIM1_Init(); // PWM for motor and ADC injection group trigger
    MX_TIM2_Init(); // PWM for TFT backlight and LED
    MX_TIM3_Init(); // rotary encoder
    MX_TIM4_Init(); // mt6701 encoder
    MX_TIM5_Init(); // analog rpm counter
    MX_TIM6_Init(); // PID timer callback
    MX_TIM7_Init(); // microseconds tick timer
    MX_DAC_Init();
    #if HAVE_USB_DEVICE
        MX_USB_DEVICE_Init();
    #endif
    EXTI_Init();
    setup();
    // user init
    user_setup();

    // main loop
    while (1) {
        loop();
    }
}

// EOF

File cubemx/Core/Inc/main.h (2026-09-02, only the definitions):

#define PID_INTERVAL                                2.0f
#define VERSION_MAJOR                               1
#define VERSION_MINOR                               0
#define VERSION_PATCH                               3
#define VERSION_FULL                                ((VERSION_MAJOR << 16) | (VERSION_MINOR << 8) | (VERSION_PATCH))
#define PCB_REV_MAJOR                               1
#define PCB_REV_MINOR                               2
#define PCB_REV_FULL                                (PCB_REV_MAJOR << 8) | (PCB_REV_MINOR)
#define F_CPU                                       72000000UL
#define MT6701_PROGRAM_PPR                          false
#define TFT_DMA_CH                                  DMA1_Channel5
#define TFT_DMA                                     DMA1
#define PID_MOTOR_PWM_TIMER                         TIM1
#define ENC1_ANALOG_Pin GPIO_PIN_1
#define ENC1_ANALOG_GPIO_Port GPIOA
#define ISENSE_Pin GPIO_PIN_2
#define ISENSE_GPIO_Port GPIOA
#define VSENSE_Pin GPIO_PIN_3
#define VSENSE_GPIO_Port GPIOA
#define DRVOCP_VREF_Pin GPIO_PIN_4
#define DRVOCP_VREF_GPIO_Port GPIOA
#define OCP_VREF_Pin GPIO_PIN_5
#define OCP_VREF_GPIO_Port GPIOA
#define ENC2_A_Pin GPIO_PIN_6
#define ENC2_A_GPIO_Port GPIOA
#define ENC2_B_Pin GPIO_PIN_7
#define ENC2_B_GPIO_Port GPIOA
#define EXT_NTC_Pin GPIO_PIN_4
#define EXT_NTC_GPIO_Port GPIOC
#define DRV_TEMP_Pin GPIO_PIN_5
#define DRV_TEMP_GPIO_Port GPIOC
#define LED_PWM_Pin GPIO_PIN_10
#define LED_PWM_GPIO_Port GPIOB
#define TFT_PWM_Pin GPIO_PIN_11
#define TFT_PWM_GPIO_Port GPIOB
#define OCP_INT_Pin GPIO_PIN_12
#define OCP_INT_GPIO_Port GPIOB
#define OCP_INT_EXTI_IRQn EXTI15_10_IRQn
#define TFT_CLK_Pin GPIO_PIN_13
#define TFT_CLK_GPIO_Port GPIOB
#define DRV_FAULT_Pin GPIO_PIN_14
#define DRV_FAULT_GPIO_Port GPIOB
#define DRV_FAULT_EXTI_IRQn EXTI15_10_IRQn
#define TFT_MOSI_Pin GPIO_PIN_15
#define TFT_MOSI_GPIO_Port GPIOB
#define BTN_1_Pin GPIO_PIN_8
#define BTN_1_GPIO_Port GPIOD
#define BTN_1_EXTI_IRQn EXTI9_5_IRQn
#define BTN_2_Pin GPIO_PIN_9
#define BTN_2_GPIO_Port GPIOD
#define BTN_2_EXTI_IRQn EXTI9_5_IRQn
#define BTN_3_Pin GPIO_PIN_10
#define BTN_3_GPIO_Port GPIOD
#define BTN_3_EXTI_IRQn EXTI15_10_IRQn
#define DRV_SNSOUT_Pin GPIO_PIN_11
#define DRV_SNSOUT_GPIO_Port GPIOD
#define DRV_SNSOUT_EXTI_IRQn EXTI15_10_IRQn
#define MOTOR_LEDS_Pin GPIO_PIN_12
#define MOTOR_LEDS_GPIO_Port GPIOD
#define TFT_CS_Pin GPIO_PIN_15
#define TFT_CS_GPIO_Port GPIOD
#define TFT_RST_Pin GPIO_PIN_6
#define TFT_RST_GPIO_Port GPIOC
#define TFT_DC_Pin GPIO_PIN_7
#define TFT_DC_GPIO_Port GPIOC
#define DRV_IN1_Pin GPIO_PIN_8
#define DRV_IN1_GPIO_Port GPIOA
#define DRV_IN2_Pin GPIO_PIN_9
#define DRV_IN2_GPIO_Port GPIOA
#define USB_DN_Pin GPIO_PIN_11
#define USB_DN_GPIO_Port GPIOA
#define USB_DP_Pin GPIO_PIN_12
#define USB_DP_GPIO_Port GPIOA
#define SWDIO_Pin GPIO_PIN_13
#define SWDIO_GPIO_Port GPIOA
#define SWCLK_Pin GPIO_PIN_14
#define SWCLK_GPIO_Port GPIOA
#define PAD_TX4_Pin GPIO_PIN_10
#define PAD_TX4_GPIO_Port GPIOC
#define PAD_RX4_Pin GPIO_PIN_11
#define PAD_RX4_GPIO_Port GPIOC
#define ENC1_I2C_EN_Pin GPIO_PIN_7
#define ENC1_I2C_EN_GPIO_Port GPIOD
#define SWO_Pin GPIO_PIN_3
#define SWO_GPIO_Port GPIOB
#define ENC1_SCL_Pin GPIO_PIN_6
#define ENC1_SCL_GPIO_Port GPIOB
#define ENC1_SDA_Pin GPIO_PIN_7
#define ENC1_SDA_GPIO_Port GPIOB
#define SCL1_Pin GPIO_PIN_8
#define SCL1_GPIO_Port GPIOB
#define SDA1_Pin GPIO_PIN_9
#define SDA1_GPIO_Port GPIOB
#define USB_PU_EN_Pin GPIO_PIN_1
#define USB_PU_EN_GPIO_Port GPIOE

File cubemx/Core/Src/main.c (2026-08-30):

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
/* Includes ------------------------------------------------------------------*/
#include "main.h"
#include "usb_device.h"

CRC_HandleTypeDef hcrc;

DAC_HandleTypeDef hdac;

TIM_HandleTypeDef htim1;
TIM_HandleTypeDef htim2;
TIM_HandleTypeDef htim3;
TIM_HandleTypeDef htim4;
TIM_HandleTypeDef htim5;
TIM_HandleTypeDef htim6;
TIM_HandleTypeDef htim7;

WWDG_HandleTypeDef hwwdg;

void SystemClock_Config(void);
/**
  * @brief  The application entry point.
  * @retval int
  */

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
/* USER CODE BEGIN 4 */

enum InterruptErrorType interruptErrorType = ERROR_HANDLER;

/* USER CODE END 4 */
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


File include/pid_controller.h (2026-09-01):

/**
  Author: sascha_lammers@gmx.de
*/

#pragma once

#include "helpers.h"
#include "main.h"
#include "eeprom.h"
#include "stats.h"
#include "leds.h"

// 32bit floating point ~1800 clock cycles
// int64_t fixed point ~580 clock cycles
// the code has changed since i measured this, but the difference is still significant
#ifndef PID_USE_FLOATING_POINT_MATH
#define PID_USE_FLOATING_POINT_MATH 0
#endif

struct PidController
{
    #if PID_USE_FLOATING_POINT_MATH
    using PidValueType = float;
    #else
    using PidValueType = int32_t;
    #endif

    static constexpr uint32_t kReleaseBrakeTimeMillis = 5000;                           // time to release the brake after motor is turned off
    static constexpr uint32_t kInitialSensorCheckTimeMillis = 750;                      // time to initially check for motor stall and sensor errors

    static constexpr uint16_t kPPR = 1024;                                              // MT6701 PPR
    static constexpr uint16_t kCPR = kPPR * 4;                                          // 4x Mode PPR to CPR
    static constexpr float kPIDInterval = PID_INTERVAL;                                 // PID update rate in millis used for precise RPM calculation
    static constexpr uint16_t kAntiWindup = 90 * UIConstants::kAntiWindupFactor;        // reduce integral if error is out of range (90%)
    static constexpr bool kProgramPPR = MT6701_PROGRAM_PPR;                             // set to true to program the MT6701 encoder during boot over i2c
    static constexpr uint32_t kMaxRPM = 55000;                                          // max. supported RPM by the encoder
    static constexpr float kMaxError = kCPR / (60000 / kPIDInterval) * kMaxRPM;         // factor to reduce error to a value between -1.0 and 1.0 for the PID loop
    #if PID_USE_FLOATING_POINT_MATH
        static constexpr int32_t kFPFactor = 1;
    #else
        static constexpr int32_t kFPFactor = kMaxError;
    #endif

    // convert RPM to counts per PID interval
    static constexpr uint32_t kRPMToIntCounts(uint32_t value)
    {
        return static_cast<uint32_t>((value * kCPR) / static_cast<int32_t>(60000 / kPIDInterval));
    }

    template<int32_t VALUE>
    static constexpr uint32_t kRPMToIntCountsT()
    {
        return kRPMToIntCounts(VALUE);
    }

    // convert counts per PID interval to RPM
    static constexpr int32_t kIntCountsToRPM(int32_t value)
    {
        return static_cast<int32_t>((value * static_cast<int32_t>(60000 / kPIDInterval)) / kCPR);
    }

    enum class ErrorCodeType : int32_t {
        NONE = 0,
        STALL,
        SENSOR,
        SENSOR_REVERSE,
        MOTOR_OVER_TEMPERATURE,
        MOSFET_OVER_TEMPERATURE,
        OVP
    };

    /**
     * @brief Construct a new Pid Controller object
     *
     */
    PidController() :
        rpm(0),
        motorDirection(EEPROM::MotorDirection::Forward),
        antiWindup(kAntiWindup),
        errorCode(ErrorCodeType::NONE),
        running(false),
        releaseBrakeCounter(0)
    {
        setKp(UIConstants::kDefaultKp);
        setKi(UIConstants::kDefaultKi);
        setKd(UIConstants::kDefaultKd);
    }

    /**
     * @brief Construct a new Pid Controller object
     *
     * @param Kp
     * @param Ki
     * @param Kd
     */
    PidController(float Kp, float Ki, float Kd)
    {
        setKp(Kp);
        setKi(Ki);
        setKd(Kd);
    }

    /**
     * @brief Set the Kp value and pre-calculate KpPreCalc for PID loop
     *
     * @param value The new Kp value
     */
    inline void setKp(float value)
    {
        Kp = value;
        KpPreCalc = value * pwmLevel.getMax();
        SWO::data.Kp = value;
    }

    /**
     * @brief Set the Ki value and pre-calculate KiPreCalc for PID loop
     *
     * @param value The new Ki value
     */
    inline void setKi(float value)
    {
        Ki = value;
        KiPreCalc = value * pwmLevel.getMax();
        SWO::data.Ki = value;
    }

    /**
     * @brief Set the Kd value and pre-calculate KdPreCalc for PID loop
     *
     * @param value The new Kd value
     */
    inline void setKd(float value)
    {
        Kd = value;
        KdPreCalc = value * pwmLevel.getMax();
        SWO::data.Kd = value;
    }

    /**
     * @brief Calculate the PWM level based on the PID error, integral, and derivative values.
     *
     * @param error The current error value
     * @param integral The integral of the error
     * @param derivative The derivative of the error
     * @return int32_t The calculated PWM level
     */
    inline int32_t calcPWMLevel(PidValueType error, PidValueType integral, PidValueType derivative) const
    {
        #if PID_USE_FLOATING_POINT_MATH
            return (error * KpPreCalc + integral * KiPreCalc + derivative * KdPreCalc);
        #else
            return (error * static_cast<int64_t>(KpPreCalc) + integral * static_cast<int64_t>(KiPreCalc) + derivative * static_cast<int64_t>(KdPreCalc)) / kFPFactor; // use int64_t to avoid overflow
        #endif
    }

    /**
     * @brief Clamp the PWM level to the valid range
     *
     * @param value The PWM level to clamp
     * @return int32_t The clamped PWM level
     */
    inline int32_t clampPWMLevel(int32_t value) const
    {
        return pwmLevel.clamp(value);
    }

    /**
     * @brief Clamp RPM
     *
     * @param value The RPM value to clamp
     * @return uint32_t The clamped RPM value
     */
    inline uint32_t clampRPM(int32_t value) const
    {
        return std::clamp<int32_t>(value, 0, kMaxRPM);
    }

    /**
     * @brief Set target RPM and update limits
     *
     * @param value
     */
    inline void setRPM(uint32_t value)
    {
        // PID tuning via SWO
        SWO::data.rpm = value;
        // rev. per minute
        rpm = value;
        // RPM to counts per PID interval
        countsPerInterval = kRPMToIntCounts(rpm);
    }

    /**
     * @brief Set the Anti Windup
     *
     * @param value Anti-windup factor as EEPROM value not percent
     */
    inline void setAntiWindup(uint16_t value)
    {
        antiWindup = value ? std::clamp<PidValueType>(value, UIConstants::kLowestAntiWindup, UIConstants::kMaxAntiWindup) : 0;
        SWO::data.antiWindup = value;
    }

    /**
     * @brief Get target RPM
     *
     * @return uint32_t
     */
    inline uint32_t getRPM() const
    {
        return rpm;
    }

    /**
     * @brief Set the motor direction
     *
     * @param forward
     */
    void setMotorDirection(bool forward)
    {
        motorDirection = forward ? EEPROM::MotorDirection::Forward : EEPROM::MotorDirection::Reverse;
    }

    /**
     * @brief Return true if the motor direction is forward, false otherwise
     *
     * @return true
     * @return false
     */
    bool isForwardMotorDirection() const
    {
        return motorDirection == EEPROM::MotorDirection::Forward;
    }
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

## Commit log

2026-07-14 replaced Wire with I2C class
    [main.cpp]
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2026-07-15 TFT driver and LVGL support added
2026-07-16 TFT driver updated and LVGL UI added
2026-07-17 fixed tft backlight value
    [tft_driver.cpp]
2026-07-18 driver for st7789 and st7735
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2026-07-18 changed pin assignment doc.
2026-07-18 Refactor button handling and update pin assignments
2026-07-18 pin changes and ui code
2026-07-18 timer2 channel 3 added
2026-07-18 Refactor LED handling and rotary encoder logic; update brightness settings and clean up unused functions
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2026-07-19 Add diagnostics screen and update menu structure
    - Introduced DiagnosticsScreen for displaying system diagnostics.
    - Updated menu items to include Diagnostics option.
    - Enhanced ADC handling for input and motor current limits.
    - Improved float formatting for current display.
    - Adjusted PCB revision constants and UI constants for better clarity.
2026-07-19 added I2C for EEPROM
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2026-07-20 debug code, fixes and motor enabled
    [eeprom.cpp, main.cpp, menu.cpp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]
2026-07-20 Add dashboard screen functionality and UI updates
    - Implement loadDashboardScreen in Menu class
    - Add DashboardScreen class for displaying motor information
    - Update ScreenFlow for screen transitions
    - Adjust UI constants for screen timeouts
    - Refactor button handling in Menu class
    - Introduce MinMax template for value tracking
2026-07-20 Enhance ADC functionality, update EEPROM write method to return status, and improve UI screen handling with new statistics integration
2026-07-20 Update PCB testing documentation, enhance main functionality, and refine menu and UI handling,
2026-07-21 refactoring, improved rotary encoder
2026-07-21 refactoring and some fixes
    [controls.cpp, main.cpp, menu.cpp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]
2026-07-21 pwm mode and avg rpm
2026-07-21 added sensor direction and refactoring
2026-07-21 added current, and set rpm/pwm to diagnositcs screen
2026-07-21 added rpm analog sensor counter, motor error handling for startup stall, sensor error and temperature
    [main.cpp, pid_controller.cpp, pid_controller.h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]
2026-07-22 back button to toggle motor direction, reverse sensor error detection, startup stall detection
    [main.cpp, menu.cpp, pid_controller.cpp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]
2026-07-22 removed arduino usb code
2026-07-22 USB CDC not working
    [main.c, main.cpp]
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2026-07-22 limit rpm/pwm on dashboard
2026-07-23 added framework stm32cube env
2026-07-23 fixed issues with delay() performance
    [main.cpp, tft_driver.cpp, tft_driver_st7735.cpp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]
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2026-07-24 disable pwm if the current limit is exceeded
2026-07-24 replaced some baremetal with HAL
    [adc.cpp, adc.h, controls.cpp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]
2026-07-24 HAL init and order fixed
    [adc.cpp, main.cpp, pid_controller.cpp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]
2026-07-25 added menu for pid tuning and parameters
2026-07-25 pid tuning and parameters menu, more info on start screen
2026-07-26 added pid live tuning
2026-07-26 fix for stall after motor start
2026-07-26 reset firmware only if no pid packets arrive
2026-07-26 sync PID paramters via memory writes
2026-07-26 fixed pwm % graph
2026-07-26 added anti windup reduction to the pid tuning
2026-07-26 apply pid parameters correctly
    [eeprom.cpp, menu.cpp]
2026-07-27 commit an attempt of smooth current limit whcih does not work properly
    [adc.cpp, adc.h, main.cpp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]
2026-07-27 fast current chopping as OCP
2026-07-27 fixed clamping rpm with pwm levels
    [ui_screens.cpp]
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2026-07-27 OVP protection during motor braking
2026-07-27 OVP protection, fixed wrong windup reduction factor
    [adc.cpp, menu.cpp, pid_controller.cpp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]
2026-07-27 fixed the integral windup limit, added the integral to the pid tuning, added the fault states to the pid tuing gui
    [pid_controller.cpp, pid_controller.h]
2026-07-28 using the DRV8701 to limit input current instead of PWM
2026-07-28 input current limit ramps motor current limit up and down to stay within 90-100% of the input current limit
2026-07-28 added last error to diagnositcs screen and a scrollbar, fixed signed rpm printf, renamed LEDs class methods
    [adc.cpp, main.cpp, menu.cpp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]
2026-07-29 simplified PID precalc and added asserts
2026-07-29 implemented motor stall shutdown
    [pid_controller.cpp, pid_controller.h, ui_constants.h]
2026-07-29 replaced isPressed with hasBeenPressed and improved reset method
    [controls.cpp, main.cpp, menu.cpp]
2026-07-29 fixed some UI navigation issues
    [controls.cpp, main.cpp, menu.cpp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]
2026-07-29 UI changes and fixes
    [ui.h, ui_screens.cpp]
2026-07-29 changed PID to float
2026-07-29 enable SWO pid tuning through the python script using fixed memory address
    [debug.h, main.cpp, menu.cpp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]
2026-07-29 fixed invalid anti windup value and clamping it
    [pid_controller.h]
2026-07-30 added STL files
    [enclosure_bottom.stl, enclosure_mount.stl, enclosure_mount_bottom_plate.stl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]
2026-07-30 motor brake release timeout, code cleanup
2026-07-30 stop watchdog on fatal error and signal error code with LEDs
    [main.cpp]
2026-07-30 adjust pid tuning paramters on dashboard, code cleanup and fixes
    [debug.h, main.cpp, menu.cpp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]
2026-07-30 improved UI and some fixes
    [debug.h, eeprom.cpp, main.cpp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]
2026-07-30 moved interrupt handlers and error handlers
    [adc.cpp, interrupts.cpp, main.cpp]
2026-07-30 filtered noise from temperature adc values, fixed wait timeout for debug output , fixed debug init sequence
    [adc.h, eeprom.cpp, interrupts.cpp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]
2026-08-01 fixed NTC compare method
    [adc_converters.h, main.cpp]
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2026-08-01 fixed local var names overlapping with member vars
    [stats.cpp]
2026-08-01 fixed point performance tested
    [main.cpp, pid_controller.h]
2026-08-01 zero label for sliderscreen, fixed point antiwindup
    [main.cpp, menu.cpp, pid_controller.cpp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]
2026-08-01 dont clamp 0 antiwindup value
2026-08-02 unified antiwindup and changed to fixed point
    [debug.h, interrupts.cpp, menu.cpp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]
2026-08-02 refactor: update break release time constants and improve initial sensor check logic
2026-08-02 fixed PIN
2026-08-03 refactor: enhance documentation and improve data structures for EEPROM, ADC, and controls
2026-08-03 refactor: enhance screen flow management and improve UI structure
2026-08-03 changed DAC1/DMA from cont. mode to normal to handle lower sample times
2026-08-03 moved timer handles from stack to global
2026-08-04 changed ADC DMA transfer speed and retriggering
2026-08-04 added adjustable motor pwm frequency
2026-08-04 Refactor ADC and PID controller for improved PWM frequency handling and optimization settings
2026-08-04 reduced current avg period and changed OCP protection
2026-08-04 constants for PID isr interval
2026-08-04 fixed missed pressed buttons, refresh lvgl method for screenflow, renamed debug swd to debug swo
    [debug.h, interrupts.cpp, main.cpp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]
2026-08-05 schematics and PCB rev1.1
2026-08-05 added background to start button
2026-08-06 fixed inverted min/max temperatures
    [adc_converters.h, stats.cpp]
2026-08-06 added steps for OVP 0.1V
2026-08-06 added power to dashboard
2026-08-06 high ADC update rating during breaking
2026-08-06 resetting min/max stats when starting motor, showing last error on startscreen
    [pid_controller.cpp, ui.h, ui_screens.cpp]
2026-08-06 added voltage to OVP error
    [pid_controller.cpp]
2026-08-07 added USB CDC device
2026-08-07 cleanup and error handler for watch dog hard and soft errors
    [debug.h, interrupts.cpp, main.cpp]
2026-08-07 changed ADC isr from HAL to baremetal to get 25/40% performance improvement
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2026-08-07 fixed issues with ADC restart timing, removed O3 opt. that made it slower
    [adc.cpp, adc.h, controls.cpp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]
2026-08-07 auto reset if not PID packets arrive and some fixes
2026-08-07 return to startscreen after an error occured
    [main.cpp, ui.h, ui_constants.h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]
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2026-08-08 fixed wrong type in division
    [pid_controller.cpp]
2026-08-08 missing setSteps() for antiwinup
    [menu.cpp]
2026-08-08 added RPM graph to the live pid tuning
2026-08-08 optimized graph, cleanup and fixed some signed/unsigned mixups
    [menu.cpp, pid_controller.cpp, pid_controller.h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]
2026-08-08 fixed y legend position
    [ui_screens.cpp]
2026-08-08 long press added, back button software reset after 5 seconds, long press knob for advanced menu
    [controls.cpp, interrupts.cpp, main.cpp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]
2026-08-08 fix for menu Kp parameter and better range for PID parameters
    [menu.cpp, ui_constants.h]
2026-08-08 advanced menu fix, welcome chime
    [menu.cpp, ui.h, ui_constants.h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]
2026-08-10 reset with back button inside errorhandler
    [interrupts.cpp]
2026-08-11 removed broken gamma tables and adjust colors
    [tft_driver_st7735.cpp, tft_driver_st7789.cpp, ui.h]
2026-08-11 added input and motor current limit to pid tuning
2026-08-12 init order, changed pid interval to 1.28ms to improve the response
2026-08-12 increased pid tuning buffer, added interval to the python script
2026-08-12 reduced pid tuning packet from 40 to 24 bytes
2026-08-13 code cleanup, screenshot issues fixed
    [pid_controller.cpp, pid_controller.h, tft_driver.cpp]
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2026-08-15 added crc to serial packets, screenshot issues fixed
    [main.cpp, menu.cpp, tft_driver.cpp]
2026-08-15 tested swo and serial, fixed some swo issues and cleanup/refactoring
    [debug.h, main.cpp, tft_driver.cpp]
2026-08-15 recreated cubemx files and fixed user code section
    [cubemx.ioc]
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2026-08-16 added release env, usb device id for motor_config, version increased, some cleanup
2026-08-17 improved display performance and updated DMA transfer handling, fixed DMA timeout rounding bug
    [main.cpp, tft_driver.cpp, tft_driver_st7735.cpp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]
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2026-08-23 fixed issue with invalid PID parameters after boot while the welcome screen is shown, removed unused vars from python script
    [main.cpp]
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2026-08-24 avg pwm and rpm as text in the graph
2026-08-24 pid interval macro and typo fixed
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2026-08-24 removed OCP int, changed PID timer, injection int handler
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2026-08-25 avoid clamping
2026-08-25 store PID parameters received over USB in eeprom
2026-08-25 debug code to force D+ low and re-enumerate USB device
2026-08-25 diagnostic screen PID interval and USB cable detection, PID interval updated for python tool
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2026-08-25 replaced constants with macros
    [crc.cpp, interrupts.cpp, main.cpp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]
2026-08-26 removed arduino compatibility code and cleaned up the rest of the code
2026-08-27 improved display performance by 15-25% using double buffering and DMA interrupts
2026-08-27 moved error handling to main.c/main.h
    [interrupts.cpp, main.c, main.h]
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2026-08-27 optimized DMA transfer ISR (192 cycles to 47)
2026-08-27 optimized ADC ISRs DMA1_Channel1_IRQHandler() clock cycles reduced 104-107 to 85-89 ADC1_2_IRQHandler() cycle cycles reduced from 270-284 to 173-181
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2026-08-29 added GPIO port to button class, code cleanup
2026-08-29 pid tuning on dashboard in pwm mode without the Kx parameters
2026-08-29 replaced left over C casts
    [adc.cpp, debug.h, eeprom.cpp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]
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2026-08-29 HAVE_LVGL_BUFFER_LOCK removed, fixed timeout code for tft_driver_wait_spi_sync()
    [tft_driver.cpp]
2026-08-30 replaced hal deinit/reinit code
    [motor_vibes.cpp]
2026-08-31 fix for rollback on single write
    [eeprom.cpp]
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2026-08-31 moved the fixed ram that probably caused stack/memory corruptions
    [debug.h]
2026-09-08 Add git revision tracking and update PCB revision display in diagnostics screen
    - Introduced git_revision.py script to fetch the current git commit hash.
    - Updated platformio.ini to include the new script in the build process.
    - Modified debug.h to define GIT_REVISION if not already defined.
    - Adjusted the PCB revision display in the DiagnosticsScreen to include the git revision.
    - Fixed PWM brake level calculation in PidController.

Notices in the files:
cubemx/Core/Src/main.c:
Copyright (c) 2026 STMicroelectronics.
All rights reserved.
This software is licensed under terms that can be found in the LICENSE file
